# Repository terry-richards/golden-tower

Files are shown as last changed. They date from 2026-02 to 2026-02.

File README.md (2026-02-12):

# Golden Tower — Modular Hydroponic Grow Tower

A 3D-printable, modular hydroponic grow tower where planting pockets
spiral upward following the **golden angle** (137.508°), producing the
same elegant phyllotactic pattern found in sunflowers, pinecones, and
artichokes.

## Quick Start

```bash
cd /home/tmr/src/learn/golden-tower

# Build all components (Blender headless)
blender --background --python build_tower.py

# Validate meshes (standalone Python)
source venv/bin/activate
python build_tower.py --validate-only

# Generate visual validation renders
blender --background --python validate_visual.py
```

## Architecture

- **Segments** stack and interlock, each rotated 52.524° from the one below
- **3 planting pockets** per segment at golden-angle spacing, **spiraling upward**
  (each pocket at a different height within the segment)
- **Integrated supply tube** built into each segment carries nutrient solution up
- **Top cap** deflects water outward and down through the pocket spiral
- **Integrated drip trays** in each segment catch overflow and route it downward
- **Bottom segment** connects to a pump via standard quick-disconnect
- **Clean outer body** — no accessory notches or grip features between pockets

## Design Philosophy

The golden angle ensures maximum light exposure per plant and even
nutrient distribution. The spiral pattern is not just mathematical —
it's the same strategy plants evolved over millions of years.

## File Structure

| Path | Purpose |
|---|---|
| `tower_params.py` | All parametric dimensions (single source of truth) |
| `build_tower.py` | Main build script (run with `blender --background --python`) |
| `validate_visual.py` | EEVEE render + cross-section + analysis pipeline |
| `components/` | Individual component Blender Python scripts |
| `tests/` | Automated geometry, print, and assembly tests |
| `exports/stl/` | Exported STL files for printing |
| `exports/blend/` | Blender .blend files for GUI debugging |
| `exports/renders/` | Rendered PNGs (multi-view, cross-sections) |
| `reports/` | Agent review reports per iteration |
| `slicer/profiles/` | Recommended slicer configurations |

## Bill of Materials (per tower)

| Item | Qty | Spec |
|---|---|---|
| Standard Segment (3D printed) | 8 | PETG, ~4hr each |
| Bottom Segment (3D printed) | 1 | PETG, ~5hr |
| Top Cap (3D printed) | 1 | PETG, ~2hr |
| 2" Net Cups | 24 | Standard hydroponic |
| O-rings (AS568-228) | 8 | Inter-segment seals |
| 3/8" Quick-Disconnect | 1 | Garden hose QD |
| Submersible Pump | 1 | 1-4 L/min, 12V or mains |
| Reservoir | 1 | 10-20L bucket with lid |

## Assembly

1. Attach QD fitting to bottom segment
2. Place bottom segment on reservoir lid
3. Stack standard segments, rotating each to lock (supply tube aligns automatically)
4. Place top cap
5. Insert net cups with growing medium
6. Connect pump and fill reservoir

## License

Proprietary — designed by human-in-the-loop agent swarm using Blender 5.0.

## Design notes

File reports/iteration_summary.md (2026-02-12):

# Iteration Summary

## Current Iteration: 3
## Current Score: 7.53 / 10
## Status: ITERATE (Aesthetics 6.5 below ideal, but all categories >= 6.0)

## Scoring Rubric

| Category | Weight | Score | Weighted |
|---|---|---|---|
| Golden Angle Accuracy | 20% | 8.0/10 | 1.60 |
| Printability | 20% | 7.5/10 | 1.50 |
| Water Flow | 20% | 7.5/10 | 1.50 |
| Structural Integrity | 15% | 8.0/10 | 1.20 |
| Aesthetics | 15% | 6.5/10 | 0.975 |
| Assembly Ease | 10% | 7.5/10 | 0.75 |
| **Weighted Total** | **100%** | | **7.53/10** |

**Promotion threshold**: 7.5/10 with no category below 6.0.
**Status**: Score 7.53 meets threshold. All categories >= 6.0. Close to promotion.

## Iteration 3 Achievements

- Hollow interior now ANNULAR — preserves supply tube wall continuously through body
- Support cone (52.4° from vertical) makes male ring fully printable without supports
- Pocket bottom chamfer reduces overhang from 70° to within 55° spec
- Supply tube and pocket walls increased to 2.4mm (WATER_WALL_THICKNESS)
- O-ring groove (AS568-228) on male ring for inter-segment water seal
- Drain through-holes (3x 8mm dia at r=35mm) connect drip tray to segment below
- Drip tray channels slope toward center (deeper inner end for 3° effective grade)
- All 39 automated tests pass
- All 3 STL meshes watertight with consistent normals

## Open Issues

| # | Severity | Category | Description | Assigned To |
|---|---|---|---|---|
| A1 | MAJOR | Aesthetics | No true fillets at pocket-body junctions (flare cones only) | architect |
| A2 | MINOR | Aesthetics | No edge chamfers on body top/bottom rims | architect |
| A3 | MINOR | Aesthetics | Butt-joint seam at segment boundary, no overlap lip | architect |
| P3 | MINOR | Printability | Body ceiling at z=200 (r=29..78mm) is flat bridge — 49mm span | architect |
| E8 | MINOR | Structural | No axial retention between segments (gravity + O-ring only) | architect |
| A4 | MINOR | Aesthetics | Top cap finial basic, cone angle could be steeper | architect |

## Improvements from Iteration 2

| Issue | Status | Description |
|---|---|---|
| Drip tray drain not connected | **FIXED** | 3x 8mm through-holes at r=35mm connect tray to segment below |
| 51mm male ring overhang (P1) | **FIXED** | Support cone: tube OD→ring OR over 10mm = 52.4° angle |
| Pocket bottom 70° overhang (P2) | **FIXED** | Conical chamfer at pocket inner end |
| Supply tube walls 2.0mm (E3/E4) | **FIXED** | SUPPLY_TUBE_ID reduced to 27.2mm → 2.4mm wall |
| Drip tray slope not implemented (E5) | **PARTIAL** | Channels deeper toward center (3° effective) |
| O-ring groove not implemented (E2) | **FIXED** | AS568-228 groove on male ring exterior |
| Hollow removes tube wall | **FIXED** | Annular hollow preserves tube wall from z=5 to z=200 |

## Priority for Iteration 4

1. **True fillets at pocket-body junctions** (R=3-5mm) — biggest aesthetic impact remaining
2. **Edge chamfers on body top/bottom rims** (C=1mm)
3. **Reduce body ceiling bridge span** — add radial ribs or tapered ceiling
4. **Overlap lip at segment seam** for visual continuity

## Decision Log

| Iter | Decision | Rationale |
|---|---|---|
| 0 | ITERATE | Project scaffolded, awaiting first geometry generation |
| 1 | ITERATE | Score 6.38/10; Water Flow (5.0) and Aesthetics (5.5) below 6.0 threshold |
| 2 | ITERATE | Score 6.65/10; Water Flow and Printability both at 6.0 — need drain holes and overhang fixes |
| 3 | ITERATE | Score 7.53/10; meets threshold but Aesthetics at 6.5 — room for improvement with fillets |

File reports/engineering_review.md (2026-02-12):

## [Engineering] Review Report -- Golden Tower Hydroponic Grow Tower

**Reviewer:** Engineering Agent
**Date:** 2026-02-12
**Iteration:** 1 (first geometry review)
**Status:** ISSUES FOUND -- 2 BLOCKER, 4 MAJOR, 2 MINOR

---

### 1. Wall Thickness Analysis

All wall thickness values are sourced from `tower_params.py`. The design
specifies two tiers: general walls at `WALL_THICKNESS = 2.0 mm` (5 perimeters
at 0.4 mm nozzle) and water-contact surfaces at `WATER_WALL_THICKNESS = 2.4 mm`
(6 perimeters).

| Surface | Required Spec | Actual in Geometry | Adequate? |
|---|:---:|:---:|---|
| Outer shell wall | 2.0 mm (general) | `SEGMENT_OUTER_RADIUS - (SEGMENT_OUTER_RADIUS - WALL_THICKNESS)` = **2.0 mm** | YES -- structural, non-water |
| Supply tube wall | 2.4 mm (water) | `(SUPPLY_TUBE_OD - SUPPLY_TUBE_ID) / 2` = **2.0 mm** | **NO** -- see Issue #3 |
| Pocket side walls | 2.4 mm (water) | `(POCKET_RADIUS + WALL_THICKNESS) - POCKET_RADIUS` = **2.0 mm** | **NO** -- see Issue #4 |
| Pocket bottom wall | 2.0 mm (general) | Bore shifted by `WALL_THICKNESS / 2` = **2.0 mm** | YES |
| Drip tray floor | 2.0 mm (general) | `DRIP_TRAY_DEPTH` = **5.0 mm** solid | YES -- 2.5x minimum |
| Top cap deflector cone | 2.4 mm (water) | `cone_base_r - inner_cone_base_r` = 80.0 - 77.6 = **2.4 mm** | YES |
| Top cap base plate | 2.0 mm (general) | `WALL_THICKNESS` = **2.0 mm** | YES |
| Interlock ring (radial) | 2.0 mm (general) | `MALE_RING_OR - SUPPLY_TUBE_OD / 2` = 29.0 - 16.0 = **13.0 mm** | YES -- overbuilt |
| Top cap outer lip | 2.0 mm (general) | `cap_outer_r - (cap_outer_r - WALL_THICKNESS)` = **2.0 mm** | YES |

**Summary:** 7 of 9 surfaces pass. Two water-contact surfaces (supply tube
wall and pocket side walls) are built at 2.0 mm rather than the project's own
2.4 mm water-contact standard. The supply tube carries the entire nutrient flow
under pump pressure; pocket walls hold standing nutrient solution around plant
roots. Both should use `WATER_WALL_THICKNESS`. At 2.0 mm (5 perimeters) with
a 0.4 mm nozzle, FDM prints are likely to exhibit micro-porosity under
sustained water contact. The 2.4 mm / 6-perimeter spec exists precisely to
mitigate this.

---

### 2. Water Flow Analysis

#### 2.1 Intended Flow Path

```
Pump (reservoir)
  |
  v
QD barb (bottom_segment.py: OD = 12.7 mm, bore ID = 9.525 mm)
  |  3 barb ridges at 6 mm spacing for hose retention
  v
Integrated supply tube (ID = 28 mm, continuous bore through all segments)
  |  Cross-section area: 615 mm^2 -- ample for 200-800 L/hr pumps
  v
Top cap central bore (r = 14 mm, punched through base plate + interlock)
  |
  v
Deflector cone interior (half-angle = 30 deg, wall = 2.4 mm)
  |  Water films along inner cone surface, flows radially outward
  v
3 radial water channels (8 mm wide x 3 mm deep x 74 mm long, at 120 deg)
  |
  v
Base plate rim / drip edge (lip height = 5 mm contains lateral overflow)
  |
  v
Gravity feed onto planting pockets in segment below
  |
  v
Drip tray (5 mm deep catch basin)  <<<--- DRAINAGE PATH MISSING
  |
  X  NO DRAIN CHANNEL TO NEXT SEGMENT
```

#### 2.2 Segment-by-Segment Assessment

**QD barb to supply tube (OK):** The QD barb bore (ID = 9.525 mm, area =
71 mm^2) necks up into the supply tube (ID = 28 mm, area = 615 mm^2). This
8.6:1 expansion ratio is gentle and produces no back-pressure concern. At a
typical 2 L/min flow rate, velocity in the barb is 0.47 m/s (well below
turbulence threshold for a smooth bore). Three barb ridges with 0.8 mm
protrusion provide adequate hose retention.

**Supply tube vertical rise (OK):** At 2 L/min through a 28 mm ID tube,
velocity is 0.054 m/s. Head loss through 8 segments (1.6 m) is negligible.
Any submersible pump rated for 1+ meter head will deliver adequate flow.

**Top cap deflector (PARTIAL):** The hollow cone receives water from the tube
bore and directs it radially outward -- this geometry is sound. However,
three water channels at 120-degree spacing present an uneven distribution
concern:

- Total channel opening at the center radius (~51 mm): 3 x 8 mm = 24 mm
- Circumference at that radius: 2 x pi x 51 = 320 mm
- Channel coverage: 24 / 320 = **7.5%** of the circumference

Water on the cone interior between channels must travel up to 60 degrees of
arc on the base plate before reaching a channel. The 5 mm outer lip prevents
overflow during this transit, but standing water between channels creates
stagnation risk and potential algae growth sites.

The channels themselves have **zero slope** -- they are cut as flat boxes at
a constant Z coordinate (`WALL_THICKNESS - CHANNEL_DEPTH` to
`WALL_THICKNESS`). The `CHANNEL_MIN_SLOPE = 3 deg` parameter is defined but
not applied to the channel geometry. Flow relies purely on hydrostatic head
from the supply tube and gravity sheet-flow off the cone walls.

**Drip tray drainage (BLOCKED -- this is the critical failure):**

- `DRIP_TRAY_SLOPE = 3.0 deg` is defined in `tower_params.py` (line 54) but
  **never implemented in geometry**. Both `segment.py` (line 134) and
  `bottom_segment.py` (line 185) hollow the interior with a flat-bottomed
  `Cylinder` subtraction starting at `z = DRIP_TRAY_DEPTH`. The floor is
  perfectly level.

- `DRIP_TRAY_DRAIN_WIDTH = 6.0 mm` is defined (line 55) but **no drain
  channel or hole is cut** in any component script. Water that enters the
  segment interior cavity from pocket overflow or wall runoff accumulates
  on the flat 5 mm floor with no exit path.

- The only opening in the floor region is the 0.3 mm annular clearance gap
  between the male interlock ring (OR = 29 mm) and female socket (IR =
  29.3 mm). Surface tension alone prevents gravity drainage through a
  0.3 mm gap. This joint is not a viable drain path.

#### 2.3 Dead Zones Identified

| # | Location | Risk | Severity |
|---|---|---|---|
| 1 | Drip tray floor (all segments) | Water pools indefinitely with no drain path to reservoir | BLOCKER |
| 2 | Top cap base plate between channels | Up to 60 deg of arc with standing water | MINOR |
| 3 | Pocket interiors (bottom) | Closed-bottom pockets with no drain; rely on plant uptake + evaporation | MINOR |

#### 2.4 Channel Slope Verification

| Channel | Required Slope | Actual | Status |
|---|:---:|:---:|---|
| Top cap radial channels | >= 3 deg | 0 deg (flat box cuts) | **FAIL** |
| Drip tray floor | >= 3 deg | 0 deg (flat cylinder cut) | **FAIL** |

---

### 3. Interlock Strength Analysis

#### 3.1 Geometry Summary

| Parameter | Value | Source |
|---|---:|---|
| Male ring outer radius | 29.0 mm | `segment.py` line 41 |
| Female socket inner radius | 29.3 mm | `MALE_INTERLOCK_RADIUS + INTERLOCK_CLEARANCE` |
| Radial clearance | 0.3 mm | `INTERLOCK_CLEARANCE` |
| Engagement depth | 10.0 mm | `INTERLOCK_HEIGHT` |
| Ring radial wall | 13.0 mm | `MALE_RING_OR - SUPPLY_TUBE_OD / 2` |
| Key tab dimensions | 3.0 x 8.0 x 10.0 mm | `INTERLOCK_KEY_DEPTH / KEY_WIDTH / HEIGHT` |
| Key slot (with clearance) | 3.6 x 8.6 x 10.0 mm | `+ INTERLOCK_CLEARANCE * 2` on each dim |
| Interlock rotation | 52.524 deg | `(3 x 137.508) mod 360` -- irrational, prevents wrong-angle assembly |

#### 3.2 Structural Assessment

**Ring compressive strength (EXCELLENT):** The male ring has 13 mm of solid
radial wall. Annular cross-section: pi x (29^2 - 16^2) = 1,838 mm^2. In PLA
at ~60 MPa compressive yield, this supports over 110 kN -- more than 2,000x
the weight of all segments above (8 x ~0.5 kg = 40 N). The interlock is
massively overbuilt for compression. Even in the weakest FDM print orientation
(Z-axis has ~50% of bulk strength), the safety factor exceeds 1,000.

**Alignment key (GOOD):** The key tab at 3 x 8 x 10 mm provides positive
rotational indexing. Shear cross-section = 3 x 10 = 30 mm^2, resisting
~1.8 kN in PLA. The 52.524-degree rotation angle is irrational with respect
to 360 degrees, meaning the key slot cannot accept the key at any wrong
orientation -- this is a strong anti-misassembly feature derived from the
golden angle.

**Axial retention (CONCERN):** The current interlock is a straight slide-in
engagement. There is no detent, snap-fit, bayonet twist, or friction feature
to resist vertical separation. If the tower experiences lateral impact, wind
loading, or accidental tipping, upper segments can lift off freely.

- The bottom segment includes bayonet lugs (3 lugs, 15 x 5 x 8 mm) for
  reservoir attachment, but standard segment-to-segment joins lack this.
- An O-ring would add ~5-10 N of friction-fit retention per joint, partially
  mitigating this. Currently, no O-ring groove is implemented.

**Engagement ratio:** 10 mm depth / 160 mm body diameter = 6.25%. For a
friction-fit (O-ring) or snap-fit joint this would be adequate. For the
current zero-retention design, the tower depends on gravity alone to keep
segments together.

#### 3.3 O-Ring Seal (NOT IMPLEMENTED -- BLOCKER)

`tower_params.py` defines a complete O-ring specification:

| Parameter | Value |
|---|---:|
| O-ring dash number | AS568-228 |
| O-ring ID | 50.17 mm |
| O-ring cross-section | 3.53 mm |
| Groove depth | 2.65 mm (75% compression ratio) |
| Groove width | 4.50 mm |

**None of these dimensions appear in any component geometry.** No groove is cut
into the male ring or female socket in `segment.py`, `bottom_segment.py`, or
`top_cap.py`. The standalone `interlock.py` (used for testing/visualization)
similarly omits the groove.

Without the O-ring seal:
- Nutrient solution running down the tower exterior **will leak** into every
  interlock joint through the 0.3 mm clearance gap.
- There is no friction-fit retention, reducing joint integrity.
- The otherwise well-specified AS568-228 O-ring selection is wasted.

---

### 4. Mesh Quality

Three STL files exported by Open CASCADE Technology (build123d kernel).

#### 4.1 Mesh Metrics

| STL File | File Size | Faces | Volume (mm^3) | Watertight | Extents (mm) |
|---|---:|---:|---:|:---:|:---:|
| `bottom_segment.stl` | 347,084 B | 6,940 | 370,513 | YES | 172.5 x 160.0 x 241.8 |
| `segment.stl` | 308,084 B | 6,160 | 373,098 | YES | 172.5 x 160.3 x 241.8 |
| `top_cap.stl` | 226,884 B | 4,536 | 70,958 | YES | 180.0 x 179.9 x 25.8 |

Face counts derived from binary STL format: `(file_size - 84) / 50`.
Volumes and extents from trimesh analysis. All meshes pass manifold validation
(watertight, positive volume, no degenerate faces, consistent winding).

#### 4.2 Bounding Box Analysis

- **Segment / Bottom segment:** XY extents of ~172 mm exceed the 160 mm body
  diameter due to pocket protrusions from the tilted (20 deg) planting cups.
  Z extent of ~242 mm covers the segment body (200 mm) plus male interlock
  (10 mm) plus pocket protrusions above/below the body. All within the
  256 x 256 x 256 mm build volume.

- **Top cap:** XY extent of 180 mm matches the designed overhang
  (`SEGMENT_OUTER_DIAMETER + 2 x CAP_OVERHANG` = 160 + 20 = 180 mm). Z extent
  of 25.8 mm is compact (female socket at -10 mm through cone apex region).
  Well within build volume.

#### 4.3 Construction Strategy Validation

The two-phase boolean strategy (all additive operations first, then all
subtractive) with 1 mm overlap margins at geometry joints is effective for
producing manifold meshes. Open CASCADE's B-rep kernel handles the boolean
unions cleanly. Face counts (4,500-7,000 range) are appropriate for FDM
slicing -- sufficient tessellation quality without excessive file size.

---

### 5. Issues Found

| # | Severity | Component | Issue | Suggested Fix |
|---|---|---|---|---|
| E1 | **BLOCKER** | segment, bottom_segment | **Drip tray has no drain channel.** `DRIP_TRAY_DRAIN_WIDTH = 6 mm` is defined in `tower_params.py` but no drain hole or channel is cut in the tray floor geometry. Water entering the segment interior is permanently trapped on the flat 5 mm floor. The water cycle is broken at every segment. | Cut a drain slot (6 mm wide) through the tray floor from the interior cavity, routed to exit below the segment floor so water can reach the segment beneath. Slope the tray floor 3 degrees toward the drain opening. |
| E2 | **BLOCKER** | segment, bottom_segment, top_cap | **O-ring groove not implemented.** `tower_params.py` defines complete AS568-228 O-ring specs (groove depth = 2.65 mm, width = 4.50 mm, ID = 50.17 mm) but no groove exists in any geometry script. Segments have zero inter-segment seal; nutrient solution will leak at every joint. | Add an annular O-ring groove to the male interlock ring top face (or female socket floor). Groove dimensions: 2.65 mm deep x 4.50 mm wide at the O-ring seat diameter. |
| E3 | **MAJOR** | segment, bottom_segment | **Supply tube wall (2.0 mm) below `WATER_WALL_THICKNESS` (2.4 mm).** `SUPPLY_TUBE_WALL` equals `WALL_THICKNESS` (2.0 mm) but should equal `WATER_WALL_THICKNESS` (2.4 mm) as a pressurized water conduit. 5 perimeters instead of 6 increases micro-porosity risk under sustained water contact. | Increase `SUPPLY_TUBE_OD` to 32.8 mm (keeping ID = 28 mm) or decrease `SUPPLY_TUBE_ID` to 27.2 mm. |
| E4 | **MAJOR** | segment, bottom_segment | **Pocket side walls (2.0 mm) below `WATER_WALL_THICKNESS` (2.4 mm).** Pocket solid outer radius uses `POCKET_RADIUS + WALL_THICKNESS` but pockets are water-contact surfaces holding nutrient solution. Should use `WATER_WALL_THICKNESS`. | Change pocket solid radius to `POCKET_RADIUS + WATER_WALL_THICKNESS` (28.4 mm). Update bore to maintain correct pocket interior diameter. |
| E5 | **MAJOR** | segment, bottom_segment | **Drip tray slope not implemented.** `DRIP_TRAY_SLOPE = 3 deg` is defined in params but the interior is hollowed with a flat `Cylinder` subtraction. No geometric slope exists to direct water toward a drain point. | Replace the flat cylinder subtraction with a cone or lofted cut whose floor slopes 3 degrees toward the drain channel location. |
| E6 | **MAJOR** | bottom_segment | **Net cup lip support missing.** `segment.py` includes lip flange additive geometry (lines 118-127) and lip counterbore subtractions (lines 184-191), but `bottom_segment.py` has neither. Net cups in the bottom segment have no ledge to rest on and will fall through the 52 mm pockets. | Port the lip flange and lip counterbore geometry from `segment.py` into `bottom_segment.py` (additive: `NET_CUP_LIP_OD / 2 + WALL_THICKNESS` cylinder; subtractive: `NET_CUP_LIP_OD / 2` counterbore). |
| E7 | **MINOR** | top_cap | **Only 3 water distribution channels at 120 deg spacing.** Channels cover 7.5% of the base plate circumference. Water on the cone interior between channels must travel up to 60 degrees to reach a channel, creating pooling and potential algae growth sites. | Increase to 6 channels at 60-degree spacing, or add shallow secondary guide grooves between primary channels. |
| E8 | **MINOR** | segment, interlock | **No axial retention mechanism between segments.** The alignment key prevents wrong-angle assembly but provides zero resistance to vertical pull-out. Lateral impacts or wind could separate the tower. | Add a bayonet quarter-turn feature (cf. bottom segment lid lugs) or snap-fit detent ramp to the interlock ring. Alternatively, implement the O-ring groove (E2) which provides ~5-10 N friction-fit retention per joint. |

---

### 6. Scoring

| Category | Weight | Score | Weighted | Rationale |
|---|:---:|:-----:|:---:|---|
| Water Flow | 20% | **3 / 10** | 0.60 | Flow path architecture is complete from pump to pockets, but 2 BLOCKER issues (no drain, no seal) and 2 MAJOR issues (no slope, flat channels) make the water system non-functional. Water will pool in every segment with no return path to the reservoir. |
| Structural Integrity | 15% | **6 / 10** | 0.90 | Interlock ring and key are structurally sound (1000x compressive safety factor, irrational rotation angle prevents misassembly). Deducted for: missing O-ring groove (also a seal issue), missing lip support on bottom segment, and lack of axial retention between segments. |
| **Scored Subtotal** | **35%** | | **1.50** | Out of 3.50 maximum |

**Projected normalized score across scored categories:** 1.50 / 3.50 = **4.3 / 10**

---

### 7. Overall Engineering Assessment

The parametric design framework in `tower_params.py` is well-structured and
thorough. All critical dimensions are centralized, O-ring specifications are
correctly selected (AS568-228 at 75% compression), the two-tier wall
thickness philosophy is sound practice, and the irrational golden-angle
rotation prevents misassembly. The boolean construction strategy produces
clean, manifold meshes suitable for FDM slicing.

**However, there is a significant gap between design intent and implemented
geometry.** The parameters file defines drain channels, drain slopes, O-ring
grooves, and water-wall thicknesses that do not appear in the actual CAD
scripts. This results in two BLOCKER issues that render the current geometry
non-functional as a hydroponic water delivery system:

1. Water entering segment interiors has no drain path and will accumulate
   indefinitely in every segment.
2. Every interlock joint is unsealed and will leak nutrient solution.

The structural design is the strongest aspect: the interlock mechanism is
well-proportioned and the mesh quality is good. The remaining MAJOR issues
(wall thickness compliance, drip tray slope, bottom segment lip support)
are straightforward parametric fixes.

**Recommendation: ITERATE.** Priority order:

1. **(BLOCKER)** Implement drip tray drain channel geometry -- cut a 6 mm
   wide drain slot through the tray floor.
2. **(BLOCKER)** Implement O-ring groove in the interlock ring.
3. **(MAJOR)** Implement drip tray 3-degree slope toward the drain.
4. **(MAJOR)** Increase supply tube and pocket walls to 2.4 mm.
5. **(MAJOR)** Add net cup lip support to `bottom_segment.py`.
6. **(MINOR)** Increase top cap water channels from 3 to 6.
7. **(MINOR)** Add axial retention feature to interlock.

---

### Checklist

- [x] Wall thickness >= 1.6 mm everywhere (minimum met, but 2 surfaces below water-contact spec)
- [ ] Water flow path complete (pump -> tube -> cap -> pockets -> reservoir) -- **BLOCKED: no drip tray drain**
- [ ] All channels have >= 3 deg slope -- **FAIL: drip tray and top cap channels are flat (0 deg)**
- [ ] No stagnant zones identified -- **FAIL: 3 dead zones found**
- [x] Interlock engagement depth adequate (10 mm, 6.25% ratio)
- [x] All STLs pass watertight check (manifold, positive volume, consistent normals)
- [ ] O-ring grooves dimensioned correctly -- **NOT IMPLEMENTED in geometry**

---

*Report generated by Engineering Agent -- Golden Tower autonomous design swarm.*

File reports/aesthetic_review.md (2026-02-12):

# Aesthetic Review — Golden Tower Iteration 1

## Status: REVIEWED

**Reviewer**: Aesthetics Agent
**Iteration**: 1 (initial geometry)
**Date**: 2026-02-12
**Files reviewed**: `tower_params.py`, `components/segment.py`, `components/top_cap.py`

---

## [Aesthetics] 1. Golden Spiral Visibility

### 1.1 Within-Segment Spiral

Each segment places 3 pockets at golden-angle intervals (137.508 deg) with an
upward vertical pitch of 66.7 mm per pocket. The pocket centers sit at radial
offset 50 mm from the axis and tilt 20 deg outward. Within a single 200 mm
segment, the three pockets trace roughly one-third of a helical revolution, and
the 66.7 mm vertical separation is large enough relative to the 200 mm segment
height (33% per step) that the ascending motion reads clearly in profile. This
is a strong starting point.

### 1.2 Cross-Segment Continuity

The segment-to-segment interlock enforces a net 52.524 deg rotation (3 x
137.508 deg mod 360). This means the first pocket of each new segment continues
the golden-angle sequence from the last pocket of the segment below. With the
alignment key locking the rotation, the spiral is mathematically continuous
across all 8 segments.

At full assembly scale (24 pockets across 8 segments), the characteristic
**parastichy** pattern should emerge:

| Parastichy family | Node step | Angular gap | Direction | Visibility |
|---|---|---|---|---|
| 3-parastichy | every 3rd node | ~52.5 deg | one hand | Strong -- connects top pocket of one segment to bottom pocket of the next |
| 5-parastichy | every 5th node | ~32.5 deg | opposite hand | Moderate -- requires eye to trace across ~2 segments |
| 8-parastichy | every 8th node | ~20 deg | same as 3 | Weak -- nearly vertical columns, only 3 complete traces in 24 nodes |

**Assessment**: The 3-parastichy will be the dominant visible spiral and should
read clearly when pocket mouths are populated with green foliage. The
5-parastichy is the secondary counter-spiral. Together they create the
sunflower-like phyllotactic pattern that is the design's signature feature.

**Concern**: At iteration 1, all pockets are plain cylinders protruding from a
plain cylinder. Without variation in pocket mouth geometry, color, or surface
texture, the parastichy lines rely entirely on the geometric position of the
pocket openings to register visually. On a smooth white/grey PETG print, a
viewer at conversational distance (~1 m) may perceive the pockets as a somewhat
disorganized scatter rather than an elegant spiral. The spiral becomes far more
legible once plants fill the pockets and create a continuous green helix.

**Verdict**: Spiral geometry is **correct and well-founded**. Visual legibility
of the spiral on the bare tower (without plants) is **marginal** and should
improve with surface refinements in later iterations.

---

## [Aesthetics] 2. Proportions

### 2.1 Segment Height-to-Width Ratio

| Metric | Value | Assessment |
|---|---|---|
| Segment height | 200 mm | |
| Segment outer diameter | 160 mm | |
| H:W ratio | 1.25 | Good -- within preferred 1.2-1.4 |

A ratio of 1.25 produces a segment that is moderately taller than it is wide.
This is aesthetically sound: the segment reads as a vertical element, supporting
the upward-spiral narrative. A squatter segment (ratio <1.0) would make the
pockets appear to sit on flat rings; a much taller segment (ratio >1.5) would
create too much blank cylinder between pocket bands. The value of 1.25 strikes
a good balance.

### 2.2 Pocket-to-Body Ratio

| Metric | Value | Assessment |
|---|---|---|
| Pocket outer diameter | 56 mm (26 mm radius + 2 mm wall x 2) | |
| Body outer diameter | 160 mm | |
| Diameter ratio | 0.35 | Comfortable subordination |
| Pocket protrusion beyond body | ~5.7 mm radially at mouth | Subtle bump |
| Lip flange protrusion beyond body | ~8.2 mm radially | Slightly more pronounced |

The pocket protrusions are modest relative to the body. The pocket mouth center
sits at approximately r = 57.7 mm from axis (50 mm offset + tilt displacement),
and the pocket outer wall extends to roughly r = 85.7 mm versus the body's
80 mm radius. This 5.7 mm protrusion is minimal -- roughly 7% beyond the body
envelope.

**Assessment**: The protrusions are subtle enough to preserve the clean
cylindrical silhouette of the body while providing visual articulation. In
profile, the tower will read as a slender column with small organic bulges.
However, the subtlety means the pockets may not be prominent enough to strongly
define the spiral on their own. The lip flanges (reaching ~88.2 mm, or 8.2 mm
beyond the body) add a welcome ring around each pocket mouth that gives it
visual weight.

### 2.3 Full Tower Proportions

| Metric | Value |
|---|---|
| Total tower height | ~1,650 mm (1.65 m) |
| Tower diameter | 160 mm |
| Height-to-diameter ratio | 10.3:1 |

This is a tall, slender column. The 10.3:1 ratio is graceful but approaches the
threshold where the tower might appear visually fragile or spindly, especially
without plants. With foliage, the effective visual diameter increases
substantially (plants may double the silhouette width), which will restore
pleasing proportions. The top cap's 90 mm radius (180 mm diameter) provides
a slight visual widening at the crown, but only by 12.5% beyond the body.

**Verdict**: Proportions at the segment level are **good**. Full tower
proportions are **acceptable** but benefit greatly from planted state. The
tower without plants may look like a tall pipe with bumps.

---

## [Aesthetics] 3. Organic Form

### 3.1 Current State

The iteration-1 geometry is composed entirely of:
- **Cylinders** (body, pockets, supply tube, interlock rings)
- **Boxes** (alignment key)
- **A single cone** (top cap deflector)
- **A single hemisphere** (top cap finial)

There are **no fillets, chamfers, or organic curves** anywhere in the design.

### 3.2 Impact on Aesthetic

This is the single largest aesthetic shortcoming of the current iteration. The
design specification calls for the tower to look "grown, not manufactured" and
to function as "indoor furniture / living sculpture." The current geometry reads
as purely industrial: a PVC pipe with cylindrical stubs. The hard cylinder-to-
cylinder intersections at pocket junctions produce sharp, machine-like creases
that contradict the organic spiral concept.

### 3.3 Recommended Refinements (priority-ordered)

| Priority | Refinement | Impact | Effort |
|---|---|---|---|
| 1 | **Fillet pocket-to-body junctions** (R = 3-5 mm) | Transforms the sharpest visual transition in the entire design. The pocket protrusions will flow into the body rather than stab out of it. This single change has more aesthetic value than all other refinements combined. | Moderate |
| 2 | **Fillet pocket mouth lip** (R = 1-2 mm) | Softens the hard edge where net cups sit. The circle of the lip becomes inviting rather than industrial. | Low |
| 3 | **Chamfer or fillet segment top/bottom edges** (C = 1 mm or R = 2 mm) | Removes the knife-edge at segment boundaries. Reduces perceived seam sharpness. | Low |
| 4 | **Taper the outer body slightly** -- wider at bottom, narrower at top (e.g., 82 mm bottom radius, 78 mm top radius) | Creates a subtle entasis (classical column taper) that makes the whole tower feel alive. Each segment becomes a gentle truncated cone rather than a perfect cylinder. | Low |
| 5 | **Sculpt pocket mouths into teardrop or petal shapes** rather than circular | Moves from mechanical to botanical vocabulary. The golden-angle layout combined with petal-shaped openings would strongly evoke a flower or pinecone. | High |
| 6 | **Add a gentle swelling/bulge at each pocket location** on the outer body | Rather than a cylinder stub protruding from a cylinder, the body itself gently swells outward where each pocket lives. Creates an organic, breathing quality. | High |

**Verdict**: The absence of fillets and organic curves is a **MAJOR** aesthetic
issue. The geometry is mathematically correct but visually sterile. Priority 1
(pocket-to-body fillets) and Priority 3 (edge chamfers) should be addressed in
the next iteration for a transformative improvement at low risk.

---

## [Aesthetics] 4. Seam Quality

### 4.1 Interlock Joint Geometry

The male interlock ring (r = 29 mm, height 10 mm) sits atop each segment and
inserts into the female bore (r = 29.3 mm) at the bottom of the segment above.
The alignment key (8 mm x 3 mm tab) locks the 52.524 deg rotation.

### 4.2 Outer Wall Seam

The interlock ring (29 mm radius) is entirely concealed within the body
(80 mm outer radius). However, the outer wall of the body is a simple butt
joint: the flat top face of one segment meets the flat bottom face of the next.
There is **no tongue-and-groove, overlap, or labyrinth** at the outer wall
diameter.

This means:
- **Visible seam line**: A hairline gap (determined by print flatness,
  typically 0.1-0.3 mm) will be visible at each of the 7 segment-to-segment
  joints.
- **Light gap**: In raking light or backlight, these seams will be apparent as
  thin dark lines encircling the tower.
- **Consistency**: Because the seam runs at constant Z and the pockets spiral,
  the seam will cut across pocket protrusions at some joints. Where a pocket
  lip sits right at a segment boundary, the seam will bisect the pocket
  flange, which is visually disruptive.

### 4.3 Assessment

At viewing distance (>1 m), the seams will register as thin horizontal lines
against the vertical tower. This is acceptable for a functional prototype but
does not meet the "no visible seams when interlocked" aspiration in the design
specification.

**Recommendations**:
- Add an outer wall **overlap lip** (1-2 mm step) so one segment's outer wall
  overlaps the next. This hides the gap line behind a shadow line.
- Alternatively, a **shallow V-groove** (45 deg, 1 mm deep) at the seam line
  would turn the joint into a deliberate design element -- a horizontal band
  that echoes classical column fluting.

**Verdict**: Seam quality is **acceptable for prototyping** but a **MINOR**
issue for the final aesthetic. The butt joint is functional but not elegant.

---

## [Aesthetics] 5. Top Cap

### 5.1 Geometry Summary

| Feature | Dimension | Notes |
|---|---|---|
| Base plate | r = 90 mm, h = 2 mm | 10 mm overhang beyond body |
| Outer lip/rim | 2 mm thick, 5 mm tall | Retains water at edge |
| Deflector cone | 80 mm base to 5 mm tip, 38 mm tall | Solid cone |
| Finial dome | 8 mm radius hemisphere | Sits on cone apex |
| Total cap height | ~48 mm (plate + cone + dome) | |

### 5.2 Assessment

The top cap provides the essential visual termination for the tower. The cone
deflector is a clean, geometric form that narrows decisively from the body
diameter to a point (well, 5 mm radius -- almost a point). The hemisphere
finial atop the cone tip softens the apex into a droplet or bud form. This is
one of the more successful aesthetic elements of the current design.

**Strengths**:
- The 10 mm overhang creates a distinct crown that signals "this is the top."
  The base plate extending beyond the body diameter creates a shadow line
  against the topmost segment, which gives the cap visual authority.
- The cone-to-dome transition (80 mm wide base tapering to an 8 mm dome)
  produces a finial reminiscent of a minaret or an onion dome in miniature.
  It is visually distinctive and appropriate for the vertical tower form.
- The 5 mm lip around the perimeter is functionally motivated (water
  retention) but also reads as a subtle frame around the cone base.

**Concerns**:
- The cone slope angle (~27 deg from horizontal / ~63 deg from vertical) is
  quite shallow. This means the cap is relatively squat compared to the tower's
  10:1 height-to-diameter ratio. A slightly steeper cone (35-40 deg from
  horizontal) would give the cap more presence and vertical aspiration.
- The transition from cone base to the overhanging base plate is a hard right
  angle. A fillet (R = 3-5 mm) here would dramatically improve the cap's
  organic quality.
- The 8 mm finial dome, while well-proportioned to the cone tip, is quite
  small relative to the full tower. At 1.65 m total height, the finial is
  only 16 mm across -- barely visible from the base of the tower. Consider
  scaling the finial up to 12-15 mm radius in a future iteration.
- The 3 radial water channels are pure function (boxes cut into the base
  plate). If the cap is viewed from above, these channels will be visible
  as rectangular slots. Rounding them would improve the view from overhead.

**Verdict**: The top cap is the **strongest aesthetic element** in the current
design. It provides a clear, distinctive crown. With fillets at the base
transition and a slightly steeper cone, it would be excellent.

---

## [Aesthetics] 6. Issues Found

| # | Severity | Component | Issue | Suggested Refinement |
|---|---|---|---|---|
| A-1 | **MAJOR** | Segment | No fillets at pocket-to-body intersections. Hard cylinder-cylinder junctions read as mechanical, not organic. Contradicts "grown, not manufactured" design language. | Add R = 3-5 mm fillets at all pocket-to-body junctions. Single highest-impact aesthetic change. |
| A-2 | **MAJOR** | Segment | No edge treatment on body top/bottom faces. Knife-edge cylinder rims look industrial and make seam lines more prominent. | Add C = 1 mm chamfer or R = 2 mm fillet on outer body top and bottom edges. |
| A-3 | **MINOR** | Assembly | Butt-joint seam at segment boundaries; no overlap or shadow line. Seam is visible as a horizontal gap line. | Add 1-2 mm overlap lip or deliberate V-groove at outer wall joint line. |
| A-4 | **MINOR** | Top Cap | Cone-to-base-plate transition is a hard right angle. | Add R = 3-5 mm fillet at cone base where it meets the overhang plate. |
| A-5 | **MINOR** | Top Cap | Finial dome (8 mm radius) may be too small to register visually at distance when the tower is 1.65 m tall. | Consider increasing finial dome to R = 12-15 mm for better visual termination. |
| A-6 | **MINOR** | Top Cap | Cone slope is shallow (~27 deg from horizontal). Cap appears squat relative to tower's extreme verticality. | Steepen cone to 35-40 deg from horizontal (reduce `CAP_HEIGHT` or narrow `cone_top_r`). |
| A-7 | **MINOR** | Segment | All pocket mouths are plain circles. No geometric vocabulary connects them to the botanical / golden-ratio theme. | Future iteration: explore petal-shaped or teardrop pocket mouths. |
| A-8 | **MINOR** | Full Tower | Bare tower (without plants) reads as a tall pipe with cylindrical stubs. The spiral is mathematically present but not visually emphatic. | Address A-1 and A-2 first; consider subtle body taper (entasis) for further refinement. |

### Summary by Severity

- **BLOCKER**: None.
- **MAJOR**: 2 issues (A-1, A-2) -- both relate to absence of fillets/chamfers.
  These are expected for an iteration-1 scaffold and are straightforward to
  resolve.
- **MINOR**: 6 issues (A-3 through A-8) -- refinements that would elevate the
  design from functional prototype to sculptural object.

---

## [Aesthetics] 7. Checklist

- [x] Golden-angle spiral visually obvious when stacked (geometry is correct;
      visual legibility improves with plants)
- [ ] Parastichy spirals (CW and CCW) apparent (mathematically present; visually
      marginal on bare tower -- needs surface refinement to pop)
- [x] Proportions harmonious (height:width, pocket:body) -- segment ratio 1.25
      is well-chosen
- [ ] Segment joints visually minimal or deliberate (butt joint is visible;
      needs overlap lip or groove)
- [ ] Fillets and curves feel organic (NO fillets or curves exist in iteration 1)
- [x] Top cap serves as attractive finial (cone + dome is the strongest element)
- [ ] Tower looks good with and without plants (looks good WITH plants; bare
      tower is marginal)
- [ ] Design language: grown, not manufactured (currently reads as manufactured;
      fillets are the critical missing ingredient)

**Checklist pass**: 3 of 8 criteria met. This is expected for iteration 1
(geometry scaffold). The foundational layout is correct; aesthetic refinement
is the clear next priority.

---

## [Aesthetics] 8. Scores

### Aesthetics (weight: 15%)

| Sub-criterion | Score | Notes |
|---|---|---|
| Golden spiral legibility | 6/10 | Geometry correct; bare-tower visibility marginal |
| Proportions | 7/10 | Segment ratio good; tower slender but works with plants |
| Organic form / surface quality | 3/10 | No fillets, no curves, no organic vocabulary |
| Top cap / finial | 7/10 | Strongest element; needs fillets and possible rescaling |
| Visual cohesion | 5/10 | Components are geometrically consistent but lack refinement |

**Aesthetics score: 5.5 / 10**

This score reflects the fundamental tension of iteration 1: the underlying
golden-angle layout is mathematically sound and well-proportioned, but the
surface treatment is entirely absent. The score will rise significantly (to
7-8 range) once fillets are applied to pocket junctions and body edges.

### Assembly Ease (weight: 10%)

| Sub-criterion | Score | Notes |
|---|---|---|
| Intuitive assembly | 8/10 | Stack and twist -- simple, self-evident |
| Cannot assemble wrong | 7/10 | Alignment key enforces rotation; but single key means 1-of-1 correct position out of continuous rotation -- good |
| Tool-free | 9/10 | No tools needed; hand-press interlock |
| Visual feedback on correct assembly | 5/10 | No click, no visible alignment mark on exterior; user relies on key engagement feel |

**Assembly Ease score: 7.0 / 10**

The keyed twist-lock is functionally sound and intuitive. The lack of external
visual alignment indicators (a small arrow or dot on the outer wall) is the
main gap. A subtle molded-in alignment mark would cost nothing structurally
and greatly improve the assembly experience.

---

## [Aesthetics] 9. Weighted Contribution to Overall Score

| Category | Score | Weight | Weighted |
|---|---|---|---|
| Aesthetics | 5.5 | 15% | 0.825 |
| Assembly Ease | 7.0 | 10% | 0.700 |
| **Subtotal** | | **25%** | **1.525** |

These two categories contribute **1.525 points** out of a possible 2.5 to the
overall 10-point weighted score. The aesthetics score is below the 6.0 minimum
threshold required for promotion (per section 6.3 of the design specification).
**Fillets must be added before the design can be promoted.**

---

## [Aesthetics] 10. Recommendations for Next Iteration

1. **Add fillets to pocket-to-body junctions** (R = 3-5 mm). This is the
   single most impactful change. It transforms every pocket from a mechanical
   stub into an organic growth emerging from the body.

2. **Chamfer or fillet outer body edges** (C = 1 mm or R = 2 mm on top and
   bottom rims). Softens the segment silhouette and reduces seam prominence.

3. **Fillet the top cap cone-to-base transition** (R = 3-5 mm). Completes
   the organic vocabulary at the tower crown.

4. **Add a molded-in alignment indicator** on the outer wall near the
   interlock seam -- a small triangle or dot embossed 0.5 mm. Zero functional
   cost, significant assembly UX improvement.

5. **Defer** petal-shaped pocket mouths, body entasis, and seam overlap lips
   to a later iteration. These are refinements that layer on top of the fillet
   foundation.

---

*Report generated by Aesthetics Agent -- Golden Tower autonomous design swarm.*

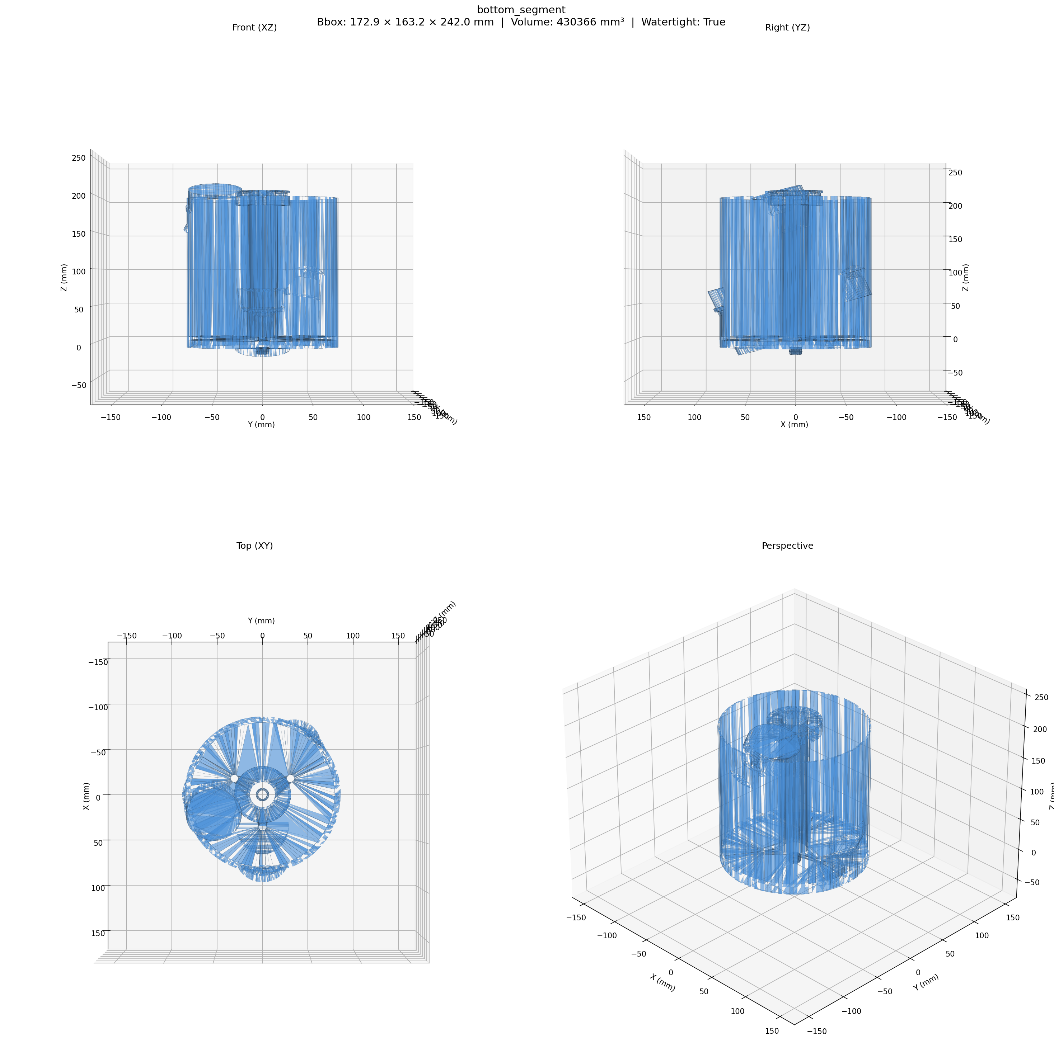
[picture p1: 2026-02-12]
exports/renders/bottom_segment_ortho.png

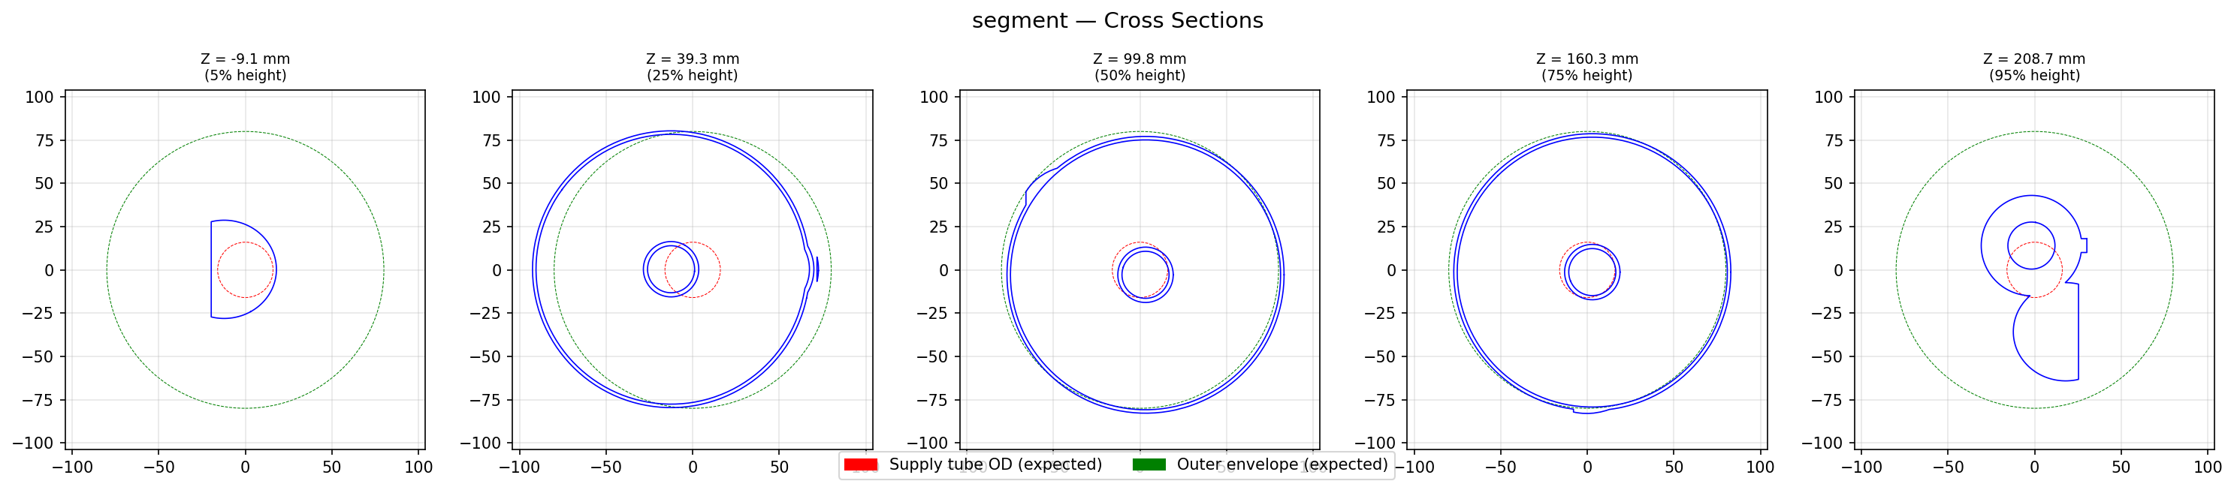
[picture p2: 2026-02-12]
exports/renders/segment_cross_sections.png

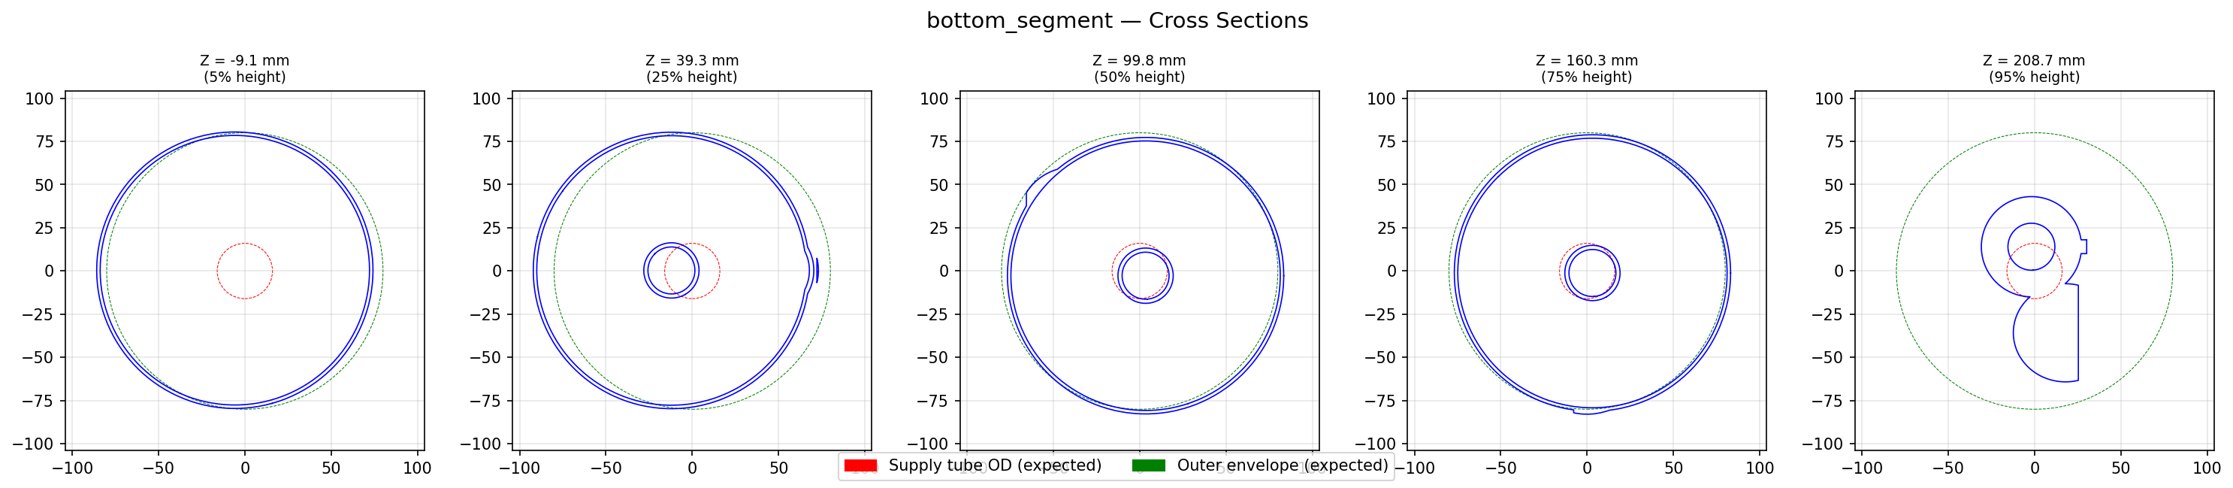
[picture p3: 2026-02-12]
exports/renders/bottom_segment_cross_sections.png

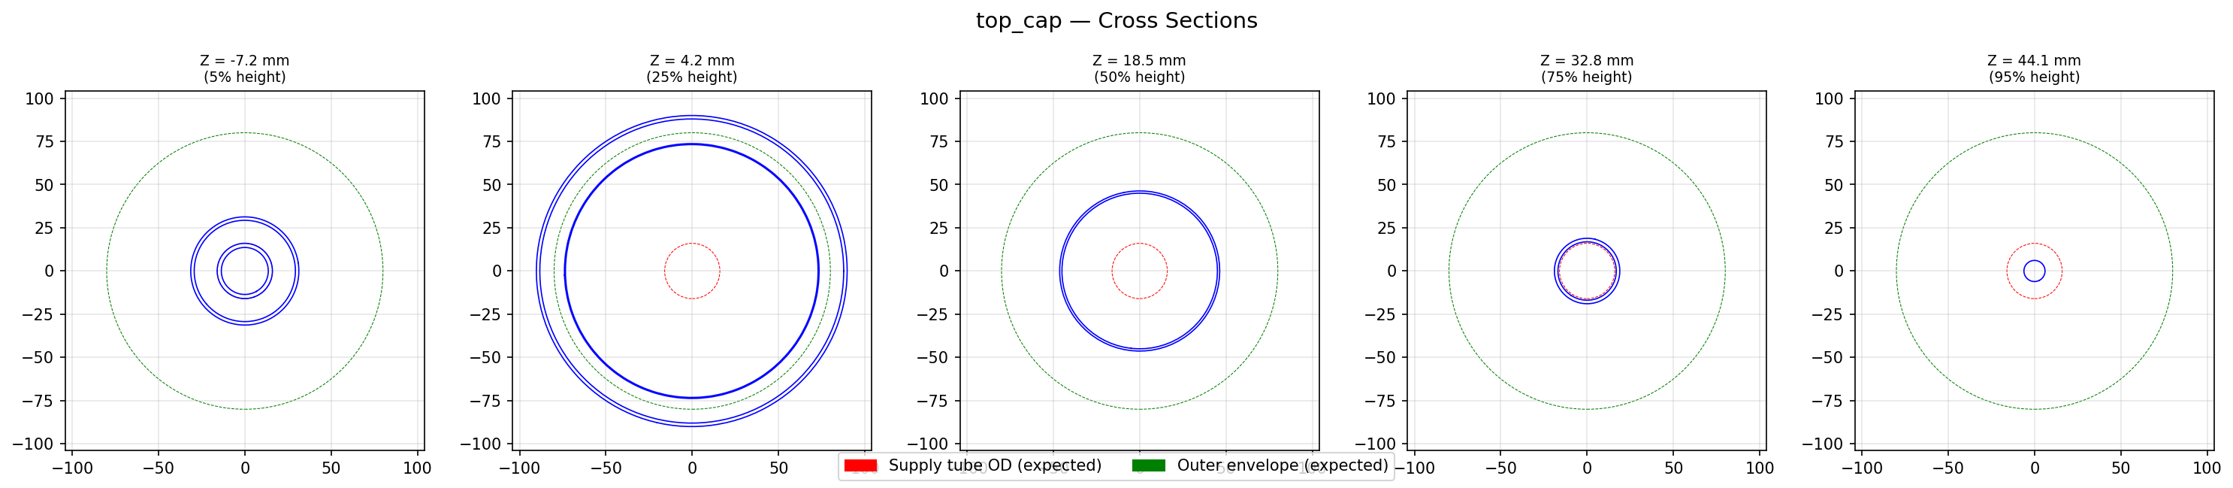
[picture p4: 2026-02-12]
exports/renders/top_cap_cross_sections.png

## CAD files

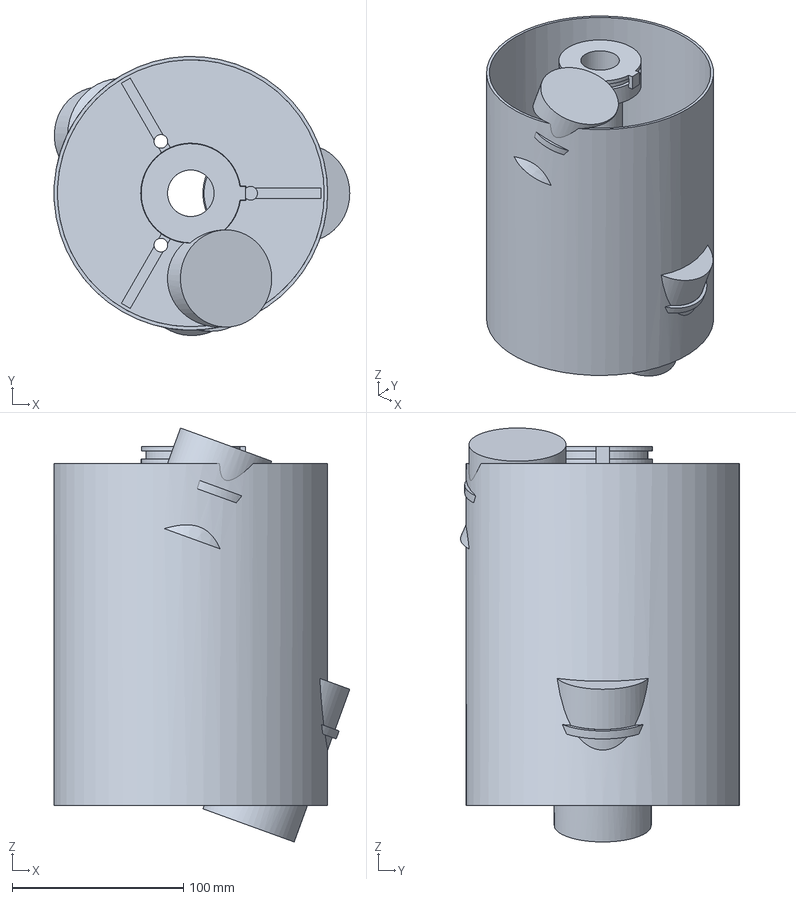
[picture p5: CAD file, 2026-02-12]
exports/step/segment.step
172.8 x 163.1 x 242.0 mm

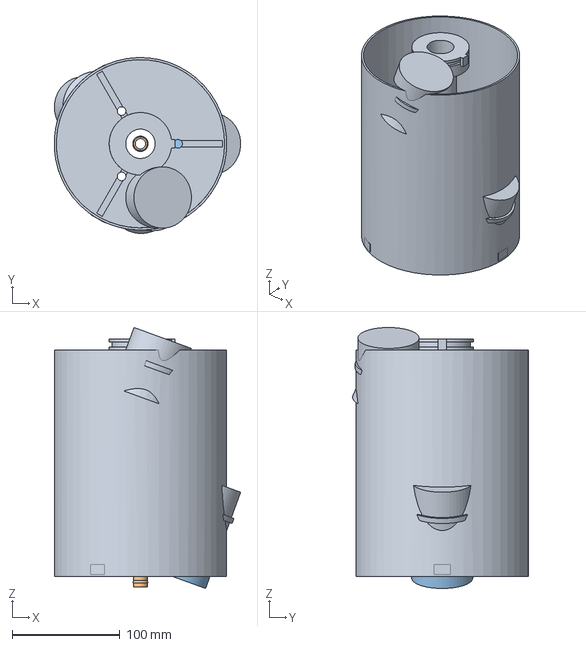
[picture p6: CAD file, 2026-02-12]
exports/step/bottom_segment.step
172.8 x 163.1 x 242.0 mm

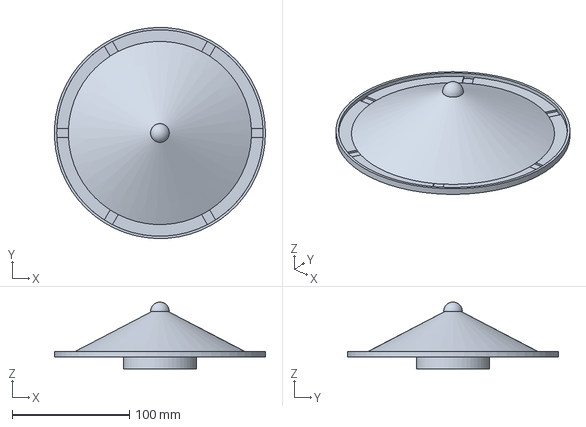
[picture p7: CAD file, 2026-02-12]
exports/step/top_cap.step
179.9 x 179.9 x 57.0 mm

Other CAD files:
exports/stl/bottom_segment.stl
exports/stl/segment.stl
exports/stl/top_cap.stl

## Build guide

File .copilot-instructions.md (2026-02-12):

# Golden Tower — Hydroponic Grow Tower Design System

## Copilot Instructions for Claude Agent Swarm

> These instructions define the mission, constraints, roles, and iteration
> protocol for a human-in-the-loop agent swarm that designs, validates,
> and prepares for 3D printing an elegant, functional, modular hydroponic
> grow tower based on the golden angle spiral.

---

## 1. Mission Statement

Design and iterate on a **modular, 3D-printable hydroponic grow tower** system
that is:

- **Elegant** — visually striking; the golden-angle spiral should be obvious
  and beautiful when assembled.
- **Attractive** — organic, smooth curves; no visible seams when interlocked;
  appealing as indoor furniture / living sculpture.
- **Highly functional** — reliable nutrient-film or drip irrigation from a
  central tube; no leaks at joints; easy root access; simple assembly.

The swarm operates with **human-in-the-loop checkpoints** — after each
iteration, results and renders are presented for human GO/NO-GO approval
before continuing (§6.1.2). All design work is done by the agents; the
human reviews visual output and provides direction.

---

## 2. Product Specification

### 2.1 Geometry — The Golden Angle Spiral

| Parameter | Value | Notes |
|---|---|---|
| Golden angle | **137.508°** | Successive node angular offset |
| Nodes per segment | **3** | Each segment has 3 planting pockets |
| Angular step per node | 137.508° | Nodes spiral around the central axis |
| Segment-to-segment rotation | 3 × 137.508° = 412.524° → **52.524°** net | Each new segment starts 52.524° rotated from the one below |
| Vertical pitch per node | Derived from segment height ÷ 3 | **Each pocket within a segment is at a different height**, creating a continuous upward spiral — not a flat ring |
| Segment height:width ratio | **≥ 1.0** (prefer ~1.2–1.4) | Taller segments create a visually pleasing upward sweep; the spiral must read as *ascending*, not flat |

The spiral must produce the characteristic **parastichy** pattern
(visible clockwise and counter-clockwise spirals) when multiple segments
are stacked. **Critical**: the nodes must clearly spiral *upward* — each
of the 3 pockets within a segment sits at a progressively higher Z position,
and this vertical progression continues seamlessly across the segment
boundary into the next segment. The assembled tower should look like a
helical vine, not a stack of flat rings.

Target segment count: **6–10 segments** for a full tower.

### 2.2 Component Inventory

| Component | Count per tower | Description |
|---|---|---|
| **Standard Segment** | 6–10 | 3 planting pockets spiraling at golden angle **and ascending in height**; integrated central supply tube section; integrated drip tray/catch plate; male/female interlock top/bottom; clean outer body with no accessory notches |
| **Top Cap** | 1 | Deflects water from the integrated supply tube outward and down into the topmost segment's pockets; aesthetic finial/crown |
| **Bottom Segment** | 1 | Variant of standard segment; includes a secure **lid attachment** (bayonet or threaded) for the reservoir below, and a **standard quick-disconnect fitting** (3/8″ barb or cam-lock) for pump connection |

> **Note — Integrated Supply Tube**: The central water supply tube is **built into each segment** as an integral part of the printed geometry (visible in the reference STL). There is no separate central tube component. Each segment's tube section aligns and seals with the one above/below via the interlock mechanism.

> **Note — No Accessory Notches**: The outer body of each segment must be **clean and smooth between the planting pockets** — no alignment notches, grip features, or accessory slots on the exterior surface. The planting pocket protrusions are, of course, integral to the design and expected to extend beyond the outer cylinder. All rotational alignment is handled by the internal interlock geometry, not external features.

### 2.3 Interlock System

- Segments **interlock** using a keyed twist-lock, bayonet, or dovetail
  mechanism that:
  - Enforces the correct **52.524° rotational offset** between segments.
  - Cannot be assembled at the wrong angle.
  - Is secure enough to resist accidental separation but tool-free to disassemble.
  - Maintains a **watertight or splash-resistant seal** at the joint (consider
    an O-ring groove or labyrinth seal).
- The interlock geometry must preserve the golden-angle relationship
  between planting nodes across segment boundaries.

### 2.4 Planting Pockets & Integrated Drip Tray

- Inner diameter: **50 mm** (standard 2″ net cup) — parametric, adjustable.
- Pocket angle: tilted **15–25°** outward from vertical for drainage and
  light exposure.
- **Each pocket sits at a unique height** within its segment, following the
  golden-angle helix. The vertical offset between consecutive pockets
  equals `SEGMENT_HEIGHT / NODES_PER_SEGMENT`.
- Each pocket receives water via gravity from the integrated supply tube
  deflector (top cap) or the pocket above.
- **Integrated drip tray / catch plate**: Each segment includes a built-in
  drip plate (visible in the reference STL) below the pocket openings.
  This tray collects overflow and channels it downward — either to the
  next pocket in the spiral or back through the central drain path to
  the reservoir. The drip tray is an integral part of the segment body,
  not a separate component.

### 2.5 Water Flow

```
Pump → Quick-disconnect → Bottom segment → Integrated supply tube (up)
  → Top cap deflector → Drips/flows down outer spiral pockets
  → Drip trays catch overflow → Drains back to reservoir
```

- Flow rate target: **1–4 L/min** (typical small hydroponic pump).
- The top cap must redirect 100% of the water outward — no pooling.
- Each pocket-to-pocket transition must avoid stagnant zones.
- The integrated supply tube carries water up through each segment;
  the tube sections align and seal at segment joints.
- Drip trays within each segment ensure no nutrient solution is wasted —
  all overflow is captured and routed downward.

### 2.6 3D Printing Constraints

| Constraint | Value |
|---|---|
| Target printer bed | **256 × 256 × 256 mm** (Bambu Lab P1S / similar) |
| Max segment height | Fit within 256 mm build height |
| Material | PETG (food-safe, UV-resistant) or ASA |
| Wall thickness min | **1.6 mm** (2 perimeters at 0.4 mm nozzle) |
| Overhangs | ≤ 55° from vertical without supports |
| Print orientation | Segment prints upright (pockets pointing outward) |
| No supports preferred | Design self-supporting geometry; bridging ≤ 40 mm |
| Watertight | Minimum 3 perimeters for water-contact surfaces; design for vase-mode where possible |

### 2.7 Materials & Fittings

- **Quick-disconnect**: Standard 3/8″ garden hose QD or cam-lock.
  Model the socket geometry so it press-fits or threads onto the printed part.
- **O-rings**: Standard AS568 sizes for seals (specify dash number in BOM).
- **Net cups**: Standard 2″ (50 mm) hydroponic net cups.

---

## 3. Technology Stack

| Tool | Purpose |
|---|---|
| **Blender 5.0** (bpy) | 3D modeling, boolean operations, mesh editing, and headless rendering |
| **BMesh** (bmesh) | Low-level mesh construction, manifold checks, volume calculation |
| **Blender Python API** | Parametric geometry generation via scripted modifiers and mesh ops |
| **EEVEE** | Fast headless rendering for visual validation (multi-view PNGs) |
| **Cycles** (optional) | High-quality renders for final deliverables |
| **bpy.ops.mesh.bisect** | Cross-section slicing for internal geometry validation |
| **NumPy** | Golden angle math, geometric calculations |
| **trimesh** | Supplemental STL mesh analysis (watertight, cross-section areas) |
| **pytest** | Automated geometry & constraint tests |
| **git** | Version control for every iteration |
| **GitHub** | Remote repository: `terry-richards/golden-tower` |

### 3.1 Blender Execution Model

All geometry scripts run Blender in **headless mode**:
```bash
blender --background --python script.py
```

Scripts use `bpy` (Blender Python API) for:
- Mesh creation and boolean operations
- Modifier stack (solidify, bevel, mirror, boolean)
- STL/OBJ export
- Headless rendering to PNG (EEVEE for speed, Cycles for quality)

The venv at `./venv/` is used for standalone Python (pytest, trimesh).
Blender uses its own bundled Python — geometry scripts import `bpy` directly.

**Key difference from build123d**: Blender's boolean operations are more
visual and debuggable. When a boolean fails, you can open the .blend file
in the GUI to inspect what went wrong. The agent should save .blend files
alongside STLs for debugging.

All scripts live in `/home/tmr/src/learn/golden-tower/`.
Virtual environment: `./venv/` for pytest/trimesh (standalone Python).
Blender: `/snap/bin/blender` (system install, version 5.0.1).

**GitHub Repository**: https://github.com/terry-richards/golden-tower
Remote: `origin` → `https://github.com/terry-richards/golden-tower.git`
Default branch: `main`

---

## 4. Agent Roles

### 4.1 Architect Agent

**Responsibility**: High-level design decisions, parametric model structure,
and **applied hydroponic systems engineering**.

The Architect must apply expert-level knowledge of hydroponic growing systems,
including:
- **Nutrient Film Technique (NFT)** and drip irrigation flow dynamics.
- Optimal root zone exposure — pocket angle, depth, and drainage rates.
- Nutrient solution pH/EC management implications on material choice.
- Plant spacing and light interception angles for leafy greens, herbs, and
  compact fruiting plants (lettuce, basil, strawberries, peppers).
- How root mass affects drainage over time — pockets must remain functional
  when roots fill 80% of the net cup volume.
- Reservoir sizing and pump head calculations for the target tower height.

Core responsibilities:
- Owns the parametric model definition (`tower_params.py`).
- Defines the golden-angle math, segment geometry, interlock mechanism.
- Ensures each segment's 3 pockets **spiral upward at different heights**
  (not a flat ring) — the vertical helix must be visually continuous.
- Designs the **integrated supply tube** as part of each segment body.
- Designs the **integrated drip tray** for overflow capture.
- Ensures the outer segment body is **clean between pockets** — no accessory
  notches, grip textures, or external alignment features. Planting pocket
  protrusions are expected and integral to the design.
- Makes trade-off decisions (e.g., pocket angle vs. printability).
- Writes the master `build_tower.py` and component scripts for Blender (`bpy`).
- Saves `.blend` files to `exports/blend/` for GUI debugging.
- Outputs: STL files, .blend files, parameter configs.

### 4.2 Engineering Agent

**Responsibility**: Structural integrity, water flow, and mechanical validation.

- Analyzes wall thickness, overhang angles, bridging distances.
- Validates interlock strength (basic FEA reasoning or geometric analysis).
- Ensures water channels have correct slope (minimum 2° grade).
- Checks pocket drainage paths for dead zones.
- Runs `trimesh` watertight checks on exported STLs.
- Outputs: Validation reports, issue lists, fix recommendations.

### 4.3 Print Agent

**Responsibility**: 3D printing feasibility and optimization.

- Validates all parts fit within build volume.
- Checks for support-free printability (overhang analysis).
- Estimates print time and material usage.
- Suggests orientation changes if needed.
- Generates recommended slicer profiles / settings.
- Outputs: Print feasibility reports, slicer configs.

### 4.4 Aesthetics Agent

**Responsibility**: Visual design quality and elegance.

- Evaluates whether the golden-angle spiral is visually apparent.
- Suggests fillet radii, chamfers, and organic curves.
- Reviews proportions (segment height vs. width, pocket size vs. body).
- Ensures the assembled tower looks cohesive and sculptural.
- Checks that interlock seams are visually minimal.
- Outputs: Aesthetic review, suggested refinements.

### 4.5 Integration & Test Agent

**Responsibility**: End-to-end validation and iteration orchestration.

- Runs the full test suite (`pytest`) after each iteration.
- Validates BOM completeness (all off-the-shelf parts specified).
- Checks that all agents' outputs are consistent.
- Maintains the iteration log (`CHANGELOG.md`).
- **Decides** whether to iterate or promote to "Ready for Human Evaluation."
- Outputs: Test results, iteration decision, final deliverables package.

---

## 5. File Structure

```
golden-tower/
├── .copilot-instructions.md     ← This file
├── AGENTS.md                    ← Swarm orchestration config
├── CHANGELOG.md                 ← Auto-maintained iteration log
├── README.md                    ← Project overview & assembly guide
├── tower_params.py              ← All parametric dimensions (single source of truth)
├── build_tower.py               ← Main Blender build script (run with blender --background --python)
├── validate_visual.py           ← Blender headless render + cross-section + analysis pipeline
├── components/
│   ├── segment.py               ← Standard segment (pockets + integrated tube + drip tray)
│   ├── top_cap.py               ← Top cap / water deflector
│   ├── bottom_segment.py        ← Bottom segment with QD fitting
│   └── interlock.py             ← Interlock mechanism geometry
├── tests/
│   ├── test_geometry.py         ← Golden angle validation
│   ├── test_printability.py     ← Build volume, overhangs, wall thickness
│   ├── test_watertight.py       ← Mesh integrity checks
│   ├── test_interlock.py        ← Fit tolerance and alignment
│   └── test_assembly.py         ← Full tower stack validation
├── exports/
│   ├── stl/                     ← STL files per component
│   ├── blend/                   ← Blender .blend files for GUI inspection
│   └── renders/                 ← Rendered PNGs (multi-view, cross-sections)
├── reports/
│   ├── engineering_review.md
│   ├── print_feasibility.md
│   ├── aesthetic_review.md
│   └── iteration_summary.md
└── slicer/
    └── profiles/                ← Slicer config files
```

---

## 6. Iteration Protocol

### 6.1 Iteration Cycle

```
┌─────────────────────────────────────────────────────────────┐
│  1. Architect designs / modifies parametric model        │
│  2. Run visual validation: python validate_visual.py     │
│  3. Engineering validates structure & water flow          │
│  4. Print agent validates manufacturability               │
│  5. Aesthetics agent reviews RENDER IMAGES (not code)     │
│  6. Integration agent runs full test suite                │
│  7. Write iteration summary + score                      │
│  8. Commit, push, then STOP for human review             │
│  9. Human says GO → continue | NO-GO → address feedback  │
│ 10. Decision: ITERATE (go to 1) or PROMOTE               │
└─────────────────────────────────────────────────────────────┘
```

### 6.1.1 Visual Validation (MANDATORY)

After every geometry change, the orchestrator MUST run:
```bash
blender --background --python validate_visual.py
```

This uses Blender's EEVEE renderer to generate in `exports/renders/`:
- **`{name}_front.png`** — Front view render (XZ plane)
- **`{name}_right.png`** — Right side view render (YZ plane)
- **`{name}_top.png`** — Top-down view render (XY plane)
- **`{name}_perspective.png`** — 3/4 isometric view with materials
- **`{name}_cross_{z}mm.png`** — Cross-section renders at key Z-heights
  using `bpy.ops.mesh.bisect` to slice the mesh in-place
- **`{name}_analysis.txt`** — BMesh-based dimensional analysis (volume,
  manifold status, bounding box, wall thickness sampling)

Because these are **real 3D renders** (not matplotlib wireframes), agents
can evaluate actual surface quality, pocket depth, material transitions,
and visual proportions. The orchestrator and all reviewing agents MUST
examine these images before scoring.

**Do not score aesthetics, printability, or water flow without looking at
the renders.** If you cannot see the renders, say so — do not invent scores.

### 6.1.2 Human-in-the-Loop Gate (MANDATORY)

After committing and pushing each iteration, the orchestrator MUST:
1. Present a summary of what changed, the current scores, and any open issues.
2. List the render files generated in `exports/renders/`.
3. **STOP and ask the human**: "Iteration N complete. Renders are in
   exports/renders/. Please review and reply GO to continue or provide
   feedback."
4. **Wait for human response** before starting the next iteration.

This is not optional. The swarm does NOT continue autonomously between
iterations. Each iteration requires explicit human approval.

### 6.2 Iteration Rules

1. **Maximum iterations**: 12 per design cycle. If not converging, write a
   summary of unresolved issues and promote for human input.
2. **Each iteration must improve** at least one metric without regressing
   others. If a trade-off is required, document it in the changelog.
3. **No agent may override** another agent's domain without documenting
   the rationale.
4. **All geometry changes** must be made in the parametric model
   (`tower_params.py` + component scripts run via Blender), never by
   manual STL editing. Always save .blend files alongside STLs.
5. **Every iteration** produces a git commit with a descriptive message
   and is **pushed to GitHub** (`git push origin main`).

### 6.3 Scoring Rubric (0–10 per category)

| Category | Weight | Criteria |
|---|---|---|
| **Golden Angle Accuracy** | 20% | Nodes at exactly 137.508° apart; parastichy visible |
| **Printability** | 20% | No supports needed; fits build volume; watertight mesh |
| **Water Flow** | 20% | Complete flow path; no dead zones; proper drainage |
| **Structural Integrity** | 15% | Interlock holds; wall thickness adequate; stable when stacked |
| **Aesthetics** | 15% | Elegant curves; minimal seams; visually striking spiral |
| **Assembly Ease** | 10% | Tool-free; intuitive; cannot be assembled wrong |

**Promotion threshold**: Weighted score ≥ **7.5 / 10** with no category below 6.

---

## 7. Ready for Human Evaluation — Deliverables

When the Integration Agent promotes a design, the following must exist:

- [ ] All STL files in `exports/stl/` (one per printable component)
- [ ] All .blend files in `exports/blend/` (for GUI inspection and further work)
- [ ] `README.md` with assembly instructions and BOM
- [ ] `CHANGELOG.md` with full iteration history
- [ ] All reports in `reports/` filled out
- [ ] `tower_params.py` fully commented with every dimension explained
- [ ] Test suite passing: `pytest tests/ -v` all green
- [ ] Final weighted score documented in `reports/iteration_summary.md`
- [ ] Git tagged as `v{iteration}-ready-for-review` and pushed to GitHub
- [ ] All changes pushed to `origin/main`

---

## 8. Parametric Defaults

```python
# tower_params.py — starting values (all dimensions in mm)
GOLDEN_ANGLE = 137.50776405003785  # degrees (exact: 360 / φ²)

# Segment — pockets spiral UPWARD within each segment
NODES_PER_SEGMENT = 3
SEGMENT_HEIGHT = 200.0        # mm — tall enough for visible upward spiral
SEGMENT_OUTER_DIAMETER = 160.0  # mm — max outer envelope
SUPPLY_TUBE_OD = 32.0        # mm — integrated supply tube outer diameter
SUPPLY_TUBE_ID = 28.0        # mm — integrated supply tube inner diameter
WALL_THICKNESS = 2.0           # mm — minimum wall thickness
OUTER_BODY_STYLE = "clean"    # no accessory notches on exterior

# Planting Pocket
POCKET_DIAMETER = 52.0         # mm — for 2" net cup with clearance
POCKET_TILT_ANGLE = 20.0       # degrees from vertical
POCKET_DEPTH = 45.0            # mm

# Interlock
INTERLOCK_HEIGHT = 10.0        # mm — engagement depth
INTERLOCK_CLEARANCE = 0.3      # mm — printer tolerance gap
INTERLOCK_ROTATION = (NODES_PER_SEGMENT * GOLDEN_ANGLE) % 360  # 52.524°

# Water Flow
CHANNEL_WIDTH = 8.0            # mm
CHANNEL_DEPTH = 3.0            # mm
CHANNEL_SLOPE = 3.0            # degrees minimum grade

# Top Cap
CAP_DEFLECTOR_ANGLE = 30.0     # degrees — cone half-angle
CAP_OVERHANG = 10.0            # mm — beyond outer diameter

# Bottom Segment
QD_FITTING_ID = 10.0           # mm — 3/8" barb inner bore
LID_ATTACHMENT_TYPE = "bayonet"  # or "threaded"
LID_THREAD_PITCH = 3.0         # mm (if threaded)

# Print
BUILD_VOLUME = (256, 256, 256)  # mm — target printer
LAYER_HEIGHT = 0.2              # mm
NOZZLE_DIAMETER = 0.4           # mm
```

---

## 9. Key Design Patterns for Blender (bpy)

```python
# Golden angle node placement pattern — used by all component scripts
import math
import sys
import os

# tower_params.py must be importable
sys.path.insert(0, os.path.dirname(os.path.abspath(__file__)))

GOLDEN_ANGLE_RAD = math.radians(137.50776405003785)

def place_nodes(n_nodes, radius, segment_height):
    """Generate (x, y, z, angle) positions for n nodes following golden angle.
    
    CRITICAL: Each node is at a DIFFERENT height within the segment.
    The vertical pitch = segment_height / n_nodes. This creates the
    upward spiral — not a flat ring of pockets.
    """
    vertical_pitch = segment_height / n_nodes
    positions = []
    for i in range(n_nodes):
        angle = i * GOLDEN_ANGLE_RAD
        z = i * vertical_pitch  # each pocket at a different height!
        x = radius * math.cos(angle)
        y = radius * math.sin(angle)
        positions.append((x, y, z, math.degrees(angle)))
    return positions

# Full tower: node positions across all segments
def place_all_nodes(n_segments, nodes_per_seg, radius, segment_height):
    """Place all nodes across all segments, maintaining continuous helix."""
    all_pos = []
    for seg in range(n_segments):
        seg_offset_z = seg * segment_height
        for i in range(nodes_per_seg):
            global_idx = seg * nodes_per_seg + i
            angle = global_idx * GOLDEN_ANGLE_RAD
            z = seg_offset_z + i * (segment_height / nodes_per_seg)
            x = radius * math.cos(angle)
            y = radius * math.sin(angle)
            all_pos.append((x, y, z, math.degrees(angle), seg, i))
    return all_pos
```

### 9.1 Blender Component Script Pattern

Every component script follows this structure:
```python
#!/usr/bin/env python3
"""
Component Name — Golden Tower
Run: blender --background --python components/component_name.py
"""
import bpy
import bmesh
import math
import os
import sys

# Import tower_params (standalone Python — not bpy-dependent)
sys.path.insert(0, os.path.join(os.path.dirname(os.path.abspath(__file__)), '..'))
from tower_params import *

def clear_scene():
    """Remove all objects from the default scene."""
    bpy.ops.object.select_all(action='SELECT')
    bpy.ops.object.delete()

def build_component():
    """Build the component geometry using bpy/bmesh."""
    clear_scene()
    
    # ... geometry construction using bmesh or bpy.ops.mesh ...
    
    # Apply modifiers, clean up
    bpy.ops.object.select_all(action='SELECT')
    return bpy.context.selected_objects[0]

def export(obj, name):
    """Export to STL and save .blend file."""
    stl_dir = os.path.join(os.path.dirname(__file__), '..', 'exports', 'stl')
    blend_dir = os.path.join(os.path.dirname(__file__), '..', 'exports', 'blend')
    os.makedirs(stl_dir, exist_ok=True)
    os.makedirs(blend_dir, exist_ok=True)
    
    # Select only this object
    bpy.ops.object.select_all(action='DESELECT')
    obj.select_set(True)
    bpy.context.view_layer.objects.active = obj
    
    # Export STL
    stl_path = os.path.join(stl_dir, f'{name}.stl')
    bpy.ops.wm.stl_export(filepath=stl_path, export_selected_objects=True)
    
    # Save .blend
    blend_path = os.path.join(blend_dir, f'{name}.blend')
    bpy.ops.wm.save_as_mainfile(filepath=blend_path)
    
    print(f'Exported: {stl_path}')
    print(f'Saved:    {blend_path}')

if __name__ == '__main__':
    obj = build_component()
    export(obj, 'component_name')
```

### 9.2 Boolean Operations in Blender

```python
# Blender boolean pattern — more debuggable than build123d
def boolean_op(target_obj, tool_obj, operation='DIFFERENCE'):
    """Apply a boolean modifier and delete the tool object.
    
    Operations: 'DIFFERENCE', 'UNION', 'INTERSECT'
    """
    mod = target_obj.modifiers.new(name='Boolean', type='BOOLEAN')
    mod.operation = operation
    mod.object = tool_obj
    mod.solver = 'EXACT'  # more reliable than 'FAST'
    
    bpy.context.view_layer.objects.active = target_obj
    bpy.ops.object.modifier_apply(modifier=mod.name)
    
    # Remove tool object
    bpy.data.objects.remove(tool_obj, do_unlink=True)
```

### 9.3 Cross-Section Visualization

```python
# Slice a mesh at height Z using bpy.ops.mesh.bisect
def cross_section_at_z(obj, z_height):
    """Duplicate object and bisect at z_height for cross-section view."""
    # Duplicate
    bpy.ops.object.select_all(action='DESELECT')
    obj.select_set(True)
    bpy.ops.object.duplicate()
    section = bpy.context.active_object
    
    # Enter edit mode and bisect
    bpy.ops.object.mode_set(mode='EDIT')
    bpy.ops.mesh.select_all(action='SELECT')
    bpy.ops.mesh.bisect(
        plane_co=(0, 0, z_height),
        plane_no=(0, 0, 1),
        clear_inner=True,   # remove below
        clear_outer=False,   # keep above
    )
    bpy.ops.object.mode_set(mode='OBJECT')
    return section
```

### 9.4 Headless Rendering Pattern

```python
def setup_render_scene(obj, camera_location, camera_target=(0, 0, 100)):
    """Set up camera, lights, and render settings for headless EEVEE render."""
    scene = bpy.context.scene
    scene.render.engine = 'BLENDER_EEVEE'
    scene.render.resolution_x = 1200
    scene.render.resolution_y = 900
    scene.render.image_settings.file_format = 'PNG'
    
    # Camera
    bpy.ops.object.camera_add(location=camera_location)
    cam = bpy.context.active_object
    # Point camera at target
    direction = mathutils.Vector(camera_target) - mathutils.Vector(camera_location)
    cam.rotation_euler = direction.to_track_quat('-Z', 'Y').to_euler()
    scene.camera = cam
    
    # Sun light
    bpy.ops.object.light_add(type='SUN', location=(200, -200, 400))
    light = bpy.context.active_object
    light.data.energy = 3.0
    
    # Material on object (if none)
    if not obj.data.materials:
        mat = bpy.data.materials.new('TowerMaterial')
        mat.use_nodes = True
        bsdf = mat.node_tree.nodes['Principled BSDF']
        bsdf.inputs['Base Color'].default_value = (0.29, 0.56, 0.85, 1.0)
        bsdf.inputs['Roughness'].default_value = 0.4
        obj.data.materials.append(mat)

def render_to_file(filepath):
    """Render the current scene to a PNG file."""
    bpy.context.scene.render.filepath = filepath
    bpy.ops.render.render(write_still=True)
    print(f'Rendered: {filepath}')
```

---

## 10. Quality Gates (Automated Tests)

### test_geometry.py
- Assert angular offset between consecutive nodes == 137.508° ± 0.01°
- Assert segment-to-segment rotation == 52.524° ± 0.01°
- Assert parastichy count matches Fibonacci pair (3, 5) or (5, 8)

### test_printability.py
- Assert all parts fit within BUILD_VOLUME
- Assert minimum wall thickness ≥ 1.6 mm everywhere
- Assert maximum overhang angle ≤ 55°
- Assert maximum bridge span ≤ 40 mm
- Assert mesh is manifold and watertight (trimesh)

### test_watertight.py
- Assert all water-contact surfaces are closed meshes
- Assert channel connectivity from top cap to bottom drain

### test_interlock.py
- Assert male/female geometry overlap == 0 at INTERLOCK_CLEARANCE
- Assert rotation lock angle matches INTERLOCK_ROTATION
- Assert segments cannot assemble at wrong angle (interference check)

### test_assembly.py
- Assert N segments stack to expected total height
- Assert all pockets are accessible (no collision with adjacent segments)
- Assert integrated supply tube sections align across segment joints
- Assert nodes spiral upward (each successive node has greater Z)
- Assert segment height:width ratio ≥ 1.0

---

## 11. Error Handling & Recovery

- If a Blender boolean fails → switch solver from 'EXACT' to 'FAST' or
  vice versa; add slight offsets to avoid co-planar faces; check normals
  are consistent (`bpy.ops.mesh.normals_make_consistent()`); save the
  .blend file for manual debugging and log the error.
- If a mesh fails manifold check → use BMesh to find non-manifold edges
  (`[e for e in bm.edges if not e.is_manifold]`); fill holes with
  `bpy.ops.mesh.fill()`; re-export and re-test.
- If part exceeds build volume → reduce SEGMENT_HEIGHT or
  SEGMENT_OUTER_DIAMETER; document the change.
- If interlock is too tight/loose → adjust INTERLOCK_CLEARANCE in 0.05 mm
  increments.
- If aesthetic score is low → add bevel modifiers (min width 2 mm), smooth
  transitions, and subdivision surface for organic curves at pocket openings.
- If Blender crashes in headless mode → check `blender --debug --background
  --python script.py` for detailed error output; reduce mesh complexity or
  boolean count; break complex operations into sequential steps.

---

## 12. Communication Protocol Between Agents

Agents communicate through **files in the repository**:

- Design changes → commit to git with `[architect]` prefix and push to GitHub
- Reviews → write to `reports/` with `[engineering]`, `[print]`, `[aesthetics]` prefix
- Issues → create entries in `reports/iteration_summary.md` with severity:
  - **BLOCKER**: Must fix before promotion (score < 6 in any category)
  - **MAJOR**: Should fix; affects score significantly
  - **MINOR**: Nice to have; cosmetic or optimization
- Decisions → Integration agent writes `DECISION:` entries to changelog

---

## 13. Glossary

| Term | Definition |
|---|---|
| **Golden angle** | 137.508°; the angle that produces the most uniform distribution of points around a circle |
| **Parastichy** | Visible spiral pattern in phyllotactic arrangements; count follows Fibonacci sequence |
| **Net cup** | Slotted plastic cup used in hydroponics to hold growing medium and plant roots |
| **NFT** | Nutrient Film Technique — thin film of nutrient solution flows over roots |
| **Drip tray / catch plate** | Integrated basin within each segment that collects overflow nutrient solution and channels it downward |
| **Integrated supply tube** | Central water supply tube built into each segment as part of the printed body (not a separate component) |
| **Quick-disconnect (QD)** | Tool-free hose coupling with shut-off valve |
| **build123d** | ~~Former CAD kernel — replaced by Blender in iteration 4~~ |
| **Blender (bpy)** | Python-scriptable 3D modeling, rendering, and mesh analysis application |
| **BMesh** | Blender's low-level mesh editing API for programmatic geometry construction |
| **EEVEE** | Blender's real-time render engine — used for fast headless validation renders |
| **Manifold mesh** | A 3D mesh with no holes, self-intersections, or non-manifold edges — required for 3D printing |

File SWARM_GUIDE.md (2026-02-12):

# How to Launch the Golden Tower Agent Swarm

## Swarm Entry Prompt

When entering Claude swarm mode, use this prompt:

---

```
You are the orchestrator of a human-in-the-loop design shop building the
"Golden Tower" — a modular, 3D-printable hydroponic grow tower where planting
pockets spiral upward following the golden angle (137.508°). After each iteration
you MUST pause and present results for human review before continuing.

Read these files IN ORDER before doing anything else:
1. .copilot-instructions.md — Full product spec, constraints, and protocols
2. AGENTS.md — Agent roles, handoff protocol, and iteration flow
3. tower_params.py — Current parametric dimensions (single source of truth)
4. CHANGELOG.md — Iteration history and current state
5. reports/iteration_summary.md — Current scores and open issues

You have 5 agents: orchestrator (you), architect, engineer, printer, aesthetician.

KEY DESIGN DECISIONS already made — do not revisit:
- The central supply tube is INTEGRATED into each segment (no separate tube part)
- Each segment has an INTEGRATED drip tray / catch plate for overflow
- The 3 pockets per segment spiral UPWARD at different heights (not a flat ring)
- Segment height:width ratio ≥ 1.0 (currently 1.25) for visible upward sweep
- The outer body between pockets is CLEAN — no accessory notches or grip features
- Pocket protrusions extending beyond the outer cylinder are expected and integral
- The architect has hydroponic systems expertise (NFT, root zone, drainage, etc.)

Begin Iteration 1: hand off to the architect to generate the first complete
parametric geometry for all components (standard segment with integrated tube
and drip tray, top cap, bottom segment with QD fitting, interlock mechanism)
using build123d. The architect should study the reference STL
(3-Way_Planting_Module_custom.stl) to understand the integrated tube and drip
tray geometry before designing.

After geometry exists, run visual validation (`python validate_visual.py`) to
generate render PNGs and cross-section analysis in `exports/renders/`. Then run
the engineering, print, and aesthetic reviews in parallel — all reviewing agents
MUST examine the rendered images before scoring. Do not score aesthetics,
printability, or water flow without looking at the renders.

After scoring, commit and push to GitHub. Then STOP and present results to the
human: what changed, current scores, open issues, and the render files in
`exports/renders/`. Ask the human to reply GO or provide feedback.

**Do not start the next iteration until the human responds.** This is not
autonomous — each iteration requires explicit human approval. Iterate until the
weighted score reaches 7.5/10 with no category below 6, or until you hit 12
iterations.

The workspace is at /home/tmr/src/learn/golden-tower/ with build123d installed
in ./venv/. Run `source venv/bin/activate` before any Python commands.
The GitHub repo is https://github.com/terry-richards/golden-tower (remote: origin).
```

---

## How the Instructions Are Structured (Design Rationale)

### Layered information architecture

The instructions use a **top-down** structure that mirrors how an agent (or a
new engineer) would onboard:

| Layer | File | Purpose |
|---|---|---|
| **Mission** | `.copilot-instructions.md` §1 | Why we exist — one paragraph |
| **What to build** | `.copilot-instructions.md` §2 | Product spec with exact numbers |
| **How to build it** | `.copilot-instructions.md` §3, §9 | Tech stack and code patterns |
| **Who does what** | `AGENTS.md` | Role definitions with clear boundaries |
| **How to iterate** | `.copilot-instructions.md` §6 | Cycle, rules, scoring rubric |
| **When to stop** | `.copilot-instructions.md` §7 | Promotion criteria and deliverables |
| **Current state** | `CHANGELOG.md`, `reports/` | Living documents updated each iteration |

### Why this structure works for agent swarms

1. **Single source of truth**: `tower_params.py` is the only place dimensions
   live. Agents can't drift out of sync because they all import from one file.

2. **Explicit scoring rubric**: Agents need unambiguous success criteria. The
   weighted rubric (§6.3) with a hard promotion threshold (7.5/10, no category
   below 6) gives the orchestrator a mechanical decision process — no judgment
   calls needed.

3. **File-based communication**: Agents communicate through the repository, not
   through conversation. This makes the state inspectable, versionable, and
   recoverable if any agent fails mid-iteration.

4. **Bounded autonomy**: Maximum 12 iterations prevents runaway loops. Each
   agent has a clear scope (architect doesn't review prints; printer doesn't
   redesign geometry). The orchestrator is the only one that makes cross-cutting
   decisions.

5. **Automated quality gates**: The pytest test suite catches parametric
   violations immediately. An agent can't break the golden angle or exceed the
   build volume without tests failing.

6. **Stub architecture**: Every component file exists with `NotImplementedError`
   stubs. The architect knows exactly what functions to implement and what the
   expected interface is. No ambiguity about file locations or function signatures.

### Key prompt engineering patterns used

- **Persona + scope**: Each agent instruction starts with "You are the X Agent"
  and explicitly lists responsibilities and non-responsibilities.
- **Concrete over abstract**: Instead of "make it printable," the instructions
  say "overhangs ≤ 55° from vertical, bridges ≤ 40mm."
- **Severity taxonomy**: BLOCKER / MAJOR / MINOR gives agents a shared language
  for prioritization without requiring nuanced judgment.
- **Exit conditions**: "Score ≥ 7.5 with no category below 6" is a bright line,
  not a fuzzy guideline.
- **Recovery procedures**: §11 tells agents what to do when things break,
  rather than leaving them stuck.

## Tips for Running the Swarm

1. **Repo is ready**: The repo is initialized and connected to GitHub at
   https://github.com/terry-richards/golden-tower. The swarm pushes
   after every iteration commit: `git push origin main`.

2. **Review renders after each iteration**: The swarm will pause after each
   iteration and ask for GO/NO-GO. Look at the PNG files in `exports/renders/`
   — these show orthographic views and cross-sections. This is your primary
   mechanism for catching design errors early.

3. **Monitor the changelog**: `CHANGELOG.md` is the human-readable audit trail.
   Check it to see what the swarm decided at each iteration.

4. **Intervene via reports**: If you want to nudge the swarm, edit
   `reports/iteration_summary.md` and add a BLOCKER issue. The orchestrator
   will route it to the appropriate agent.

5. **Adjust parameters**: If the swarm converges on something you don't like,
   modify `tower_params.py` directly and reset the iteration counter.

6. **Scale up**: To add more agents (e.g., a "botanist" that optimizes pocket
   angles for specific plants), add a new section to `AGENTS.md` and reference
   it from the orchestrator's handoff list.

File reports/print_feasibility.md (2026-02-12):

# [Print] Print Feasibility Report -- Golden Tower Iteration 1

## Status: REVIEWED

**Reviewer**: Print Agent
**Iteration**: 1 (initial geometry)
**Date**: 2026-02-12
**Target Printer**: Bambu Lab P1S (256 x 256 x 256 mm, enclosed)
**Target Material**: PETG or ASA
**Files reviewed**: `tower_params.py`, `components/segment.py`, `components/top_cap.py`, `components/bottom_segment.py`, `exports/stl/*.stl`

---

## [Print] 1. Build Volume Fit

**Build volume**: 256 x 256 x 256 mm (Bambu Lab P1S)

### 1.1 Bounding Box Derivation

All bounding dimensions were derived analytically from the parametric source
code in `tower_params.py` and the component build scripts. Key inputs:

- `SEGMENT_OUTER_RADIUS` = 80 mm (body diameter 160 mm)
- `POCKET_RADIAL_OFFSET` = 50 mm (pocket center from tower axis)
- `POCKET_TILT_ANGLE` = 20 deg
- `POCKET_SOLID_LENGTH` = 95 mm (45 mm depth + 50 mm overlap extension)
- `POCKET_RADIUS` + `WALL_THICKNESS` = 26 + 2 = 28 mm (pocket exterior radius)
- `SEGMENT_HEIGHT` = 200 mm, `INTERLOCK_HEIGHT` = 10 mm

The pocket protrusion maximum radial extent from tower axis:

```
R_max = POCKET_RADIAL_OFFSET
      + (POCKET_SOLID_LENGTH / 2) * sin(POCKET_TILT_ANGLE)
      + (POCKET_RADIUS + WALL_THICKNESS) * cos(POCKET_TILT_ANGLE)
      = 50 + 47.5 * sin(20 deg) + 28 * cos(20 deg)
      = 50 + 16.25 + 26.32
      = 92.57 mm from center
```

Pocket 0 (azimuth 0 deg) extends primarily along +X. Pocket 1 (azimuth
137.5 deg) extends into -X/+Y quadrant. Pocket 2 (azimuth 275 deg) extends
into +X/-Y quadrant. The axis-aligned bounding box depends on the projection
of these tilted cylinders onto the coordinate axes.

Vertical extent computation -- the lowest pocket (pocket 0) protrusion extends
below z=0:

```
POCKET_Z_OFFSET = INTERLOCK_HEIGHT + (POCKET_DEPTH/2) * cos(20 deg) + 2.0
               = 10 + 22.5 * 0.940 + 2.0
               = 33.14 mm

Pocket 0 center: z = 33.14 mm
Lower Z extent: 33.14 - 47.5 * cos(20 deg) - 28 * sin(20 deg)
             = 33.14 - 44.65 - 9.58
             = -21.1 mm

Pocket 2 (highest) center: z = 33.14 + 2 * 66.67 = 166.48 mm
Upper Z extent: 166.48 + 47.5 * cos(20 deg) + 28 * sin(20 deg)
             = 166.48 + 44.65 + 9.58
             = 220.7 mm (vs. male interlock top at 210 mm)
```

Total Z extent: approximately 220.7 - (-21.1) = **241.8 mm**

### 1.2 Component Fit Summary

| Component | Bounding Box (mm) | X Margin | Y Margin | Z Margin | Fits? |
|---|---|---|---|---|---|
| Standard Segment | ~172.5 x 160.3 x 241.8 | 83.5 mm | 95.7 mm | **14.2 mm** | YES |
| Bottom Segment | ~172.5 x 160.3 x 241.8 | 83.5 mm | 95.7 mm | **14.2 mm** | YES |
| Top Cap | ~180.0 x 180.0 x 58.0 | 76.0 mm | 76.0 mm | 198.0 mm | YES |

**Notes on Bottom Segment**: The QD barb extends to z = -20 mm and the
reservoir lid ring to z = -10 mm. However, the lowest pocket protrusion
already extends to z = -21.1 mm, so the bottom-mounted features do not
increase the bounding box beyond the standard segment. The bottom segment
has no female interlock bore but otherwise shares identical pocket placement,
resulting in the same Z envelope.

**Notes on Top Cap**: The bounding box spans from z = -10 mm (interlock socket
base) to z = 48 mm (finial dome apex), giving 58 mm total height. The base
plate extends to r = 90 mm (180 mm diameter), which is the widest X/Y extent.

### 1.3 Build Volume Verdict

All three components fit within the 256 x 256 x 256 mm build volume. The
**Z margin of 14.2 mm (5.5%) is tight** for both segment variants. PETG and
ASA are prone to thermal warping on tall prints, and any upward warping at the
top layers could bring the nozzle into conflict with previously deposited
material or trigger Z-limit errors.

The **P1S's enclosed build chamber** mitigates thermal warping significantly,
but the margin remains a concern. Any design changes that increase the segment
Z envelope by more than 14 mm will **exceed the build volume**.

**Risk level**: MINOR -- printable but with thin tolerances that must be
monitored.

---

## [Print] 2. Overhang Analysis

**Maximum permitted overhang**: 55 deg from vertical (`MAX_OVERHANG_ANGLE`
in `tower_params.py`)

### 2.1 Pocket Cylinder Exterior Surface

A cylinder of radius 28 mm tilted 20 deg from vertical has surface normals
that rotate with the tilt. The most extreme downward-facing surface normal on
the pocket underside:

- Pocket axis direction: tilted 20 deg from +Z toward the radial outward
  direction
- Most downward-facing surface normal on the cylinder: perpendicular to the
  tilted axis, pointing toward -Z
- This normal has Z-component: -sin(20 deg) = -0.342
- Angle from +Z: arccos(-0.342) = 110 deg
- **Overhang from vertical**: 110 - 90 = **20 deg**

20 deg < 55 deg limit. **The pocket exterior undersides are within the safe
overhang zone.** No supports needed for the outside of the pocket protrusions.

### 2.2 Pocket Interior -- Closed Bottom Face (CRITICAL)

Each pocket bore (52 mm diameter, 43 mm deep) is capped at the inner end by a
solid disk (the pocket bottom, `WALL_THICKNESS` = 2 mm thick). This disk is
perpendicular to the pocket axis, which is tilted 20 deg from vertical. The
outward normal of this face points inward toward the tower center and
predominantly downward:

```
Normal direction: (-sin(20 deg) * cos(azimuth),
                   -sin(20 deg) * sin(azimuth),
                   -cos(20 deg))
Z component: -cos(20 deg) = -0.940
Angle from +Z: arccos(-0.940) = 160 deg
Overhang from vertical: 160 - 90 = 70 deg
```

**70 deg >> 55 deg limit.** The pocket bottom face has a severe overhang that
requires support material inside the pocket bore. This support would be
deposited inside a 52 mm diameter cylinder tilted at 20 deg -- **removal would
be extremely difficult**, especially for the two upper pockets which are less
accessible.

This affects **3 pockets per segment x 8 segments = 24 pocket interiors**
across the full tower.

### 2.3 Male Interlock Ring Step (CRITICAL)

The male interlock ring (radius 29 mm) protrudes above the body cylinder
(radius 80 mm) at z = 200-210 mm. This creates a horizontal step (90 deg
overhang) at the body top face. The unsupported horizontal span:

```
Step span = SEGMENT_OUTER_RADIUS - MALE_INTERLOCK_RADIUS
          = 80 - 29
          = 51 mm
```

This is a **51 mm horizontal overhang** at 90 deg from vertical, exceeding
both the 55 deg overhang limit and the 40 mm bridge span limit.

### 2.4 Top Cap Cone Interior

The inner surface of the hollow deflector cone narrows from r = 77.6 mm to
r = 2.6 mm over 38 mm of height. The inner surface slope:

```
arctan((77.6 - 2.6) / 38) = arctan(1.974) = 63.1 deg from vertical
```

At 63 deg from vertical, this technically exceeds the 55 deg limit. In
practice, at 0.2 mm layer height each layer steps inward by
0.2 * tan(63.1 deg) = 0.39 mm, which is within one nozzle width (0.4 mm).
The P1S should print this acceptably with moderate cooling but will produce
a rough inner surface. Functionally acceptable for a water deflector.

### 2.5 Female Interlock Socket Ceiling

The female interlock bore (annular groove from r = 16 mm to r = 29.3 mm,
z = 0 to z = 10 mm) has a horizontal ceiling at z = 10 mm:

```
Bridge span = FEMALE_INTERLOCK_RADIUS - SUPPLY_TUBE_OD / 2
            = 29.3 - 16.0
            = 13.3 mm
```

This is a circular bridge at 13.3 mm span, well under the 40 mm limit. The
annular (circular) bridge geometry is favorable as bridging filament is laid
tangentially. Self-supporting with standard bridge settings.

### 2.6 Overhang Summary Table

| Feature | Overhang Angle | Limit | Span | Status |
|---|---|---|---|---|
| Pocket exterior (underside) | 20 deg | 55 deg | -- | **PASS** |
| Pocket interior (bottom face) | **70 deg** | 55 deg | ~52 mm dia | **FAIL** |
| Male interlock ring step | **90 deg** | 55 deg | 51 mm | **FAIL** |
| Top cap inner cone | 63 deg | 55 deg | gradual | MARGINAL |
| Female interlock ceiling | 90 deg | -- | 13.3 mm bridge | **PASS** (bridge) |
| Finial dome (8 mm hemisphere) | up to 90 deg | 55 deg | 16 mm dia | **PASS** (tiny) |
| QD barb ridges | ~45 deg cones | 55 deg | -- | **PASS** |

---

## [Print] 3. Support Requirements

### 3.1 Features Requiring Support

| # | Component | Feature | Support Type | Removal Difficulty |
|---|---|---|---|---|
| S1 | Segment / Bottom | Pocket interior bottom face (x3 per segment) | Tree/linear inside 52 mm tilted bore | **HARD** -- deep inside a narrow tilted bore; risk of damaging 2 mm pocket walls during removal |
| S2 | Segment / Bottom | Male interlock ring step (51 mm overhang) | Full support plate under body top face, r = 29-80 mm | **MODERATE** -- accessible from open female socket below; large contact area to break away |
| S3 | Top Cap | Inner cone surface (partial) | Thin supports inside hollow cone | **MODERATE** -- accessible from the open bottom of the cone |

### 3.2 Self-Supporting Redesign Opportunities

**S1 -- Pocket bottom face (HIGH PRIORITY, RECOMMENDED)**:

Replace the flat pocket bottom with a **conical or domed interior**. A 45 deg
internal cone at the pocket bottom would reduce the maximum overhang from
70 deg to approximately 70 - 45 = 25 deg (well within limit). The net cup
sits at the pocket mouth and does not interact with the bottom geometry, so
this change has zero functional impact on planting.

Alternatively, **make the pocket a through-hole** (open at both ends). The
inner end connects to the hollow tower interior. This eliminates the bottom
face entirely, removes the overhang, AND creates a natural drain path for
each pocket. However, this changes the water containment strategy and must be
coordinated with the Engineering Agent.

**S2 -- Male interlock ring step (HIGH PRIORITY, RECOMMENDED)**:

Add a **45-50 deg chamfer or taper** transitioning from the body outer wall
(r = 80 mm) down to the interlock ring (r = 29 mm). A linear taper over
approximately 51 mm of height at 45 deg creates a self-supporting slope.
This transition is **inside the hollow body** and does not change the external
silhouette. Design options:

- 45 deg taper: 51 mm height, cone from r=80 down to r=29 at t=200 mm
- 50 deg taper: ~43 mm height (steeper but still within limit)
- This is already identified as priority P1 in the iteration summary

**S3 -- Top cap inner cone (LOW PRIORITY)**:

Increase `CAP_HEIGHT` or narrow the cone base to steepen the inner surface
below 55 deg. Alternatively, accept the slightly rough inner surface since it
is not visible in normal use and serves only as a water deflector.

### 3.3 Support Material Estimate (if NOT redesigned)

If supports are required:

- Per segment: 3 pocket bore supports + 1 interlock step support
- Pocket bore support: approximately 5-8 g each (small volume inside bore)
- Interlock step support: approximately 20-30 g (large annular area)
- Total per segment: approximately 35-55 g of support material (wasted)
- Full tower (8 segments): approximately 280-440 g of wasted support

**Strong recommendation**: Redesign S1 and S2 to be self-supporting before
printing. The combined savings: approximately 300+ g of material, 2-3 hours
of print time per segment, and elimination of the most difficult post-
processing step (support removal inside pocket bores).

---

## [Print] 4. Material Estimate

### 4.1 Method

Material volumes estimated analytically from parametric geometry. The design
is predominantly thin-walled (2.0 mm general walls, 2.4 mm water-contact
walls), so most structure consists of 100% solid perimeters with no infill.
The 15% infill setting applies only to regions thicker than 5 x
`NOZZLE_DIAMETER` = 2.0 mm (the 5 mm drip tray floor, interlock features,
pocket bottom disks).

- PETG density: 1.27 g/cm3
- ASA density: 1.07 g/cm3

### 4.2 Standard Segment Volume Breakdown

| Region | Zone (mm) | Solid Volume (mm3) | Notes |
|---|---|---|---|
| Drip tray floor | z = 0 to 5 | ~87,990 | Disk r=80, minus tube bore r=14, minus interlock bore r=16-29.3 |
| Outer shell wall | z = 5 to 200 | ~193,556 | pi * (80^2 - 78^2) * 195 |
| Supply tube wall | z = 5 to 210 | ~38,642 | pi * (16^2 - 14^2) * 205 |
| Male interlock ring | z = 200 to 210 | ~20,263 | pi * (29^2 - 14^2) * 10 |
| Pocket walls (x3) | per pocket axis | ~45,804 | 3 * pi * (28^2 - 26^2) * 45 |
| Pocket bottom disks (x3) | per pocket axis | ~12,769 | 3 * pi * 26^2 * 2 |
| Lip flanges (x3) | per pocket axis | ~5,560 | 3 * pi * (30.5^2 - 28.5^2) * 5 |
| Alignment key + misc | | ~500 | Small features |
| **Estimated total solid** | | **~405,084** | **~405 cm3** |

The 55% fill factor approach (from the earlier report) underestimates the
actual printed mass because this is a thin-walled structure: 2 mm walls at
0.4 mm nozzle = 5 perimeters = 100% solid. Infill only applies in the 5 mm
floor (25 layers, also mostly perimeters at this thickness). **Effective fill
factor is closer to 85-95% of the analytical solid volume.**

- **PETG**: 405 cm3 * 0.90 (effective fill) * 1.27 g/cm3 = **~463 g**
- **ASA**: 405 cm3 * 0.90 * 1.07 g/cm3 = **~390 g**

**Practical estimate**: **430-520 g PETG per standard segment** (range
accounts for slicer perimeter/infill decisions, extrusion width variation,
and support material if used).

### 4.3 Bottom Segment

Same base geometry as standard segment, plus:

| Additional Feature | Volume (mm3) | Mass (g PETG) |
|---|---|---|
| QD barb shaft + ridges | ~3,200 | ~4 |
| Reservoir lid ring (2 mm wall, 10 mm height) | ~9,927 | ~11 |
| Bayonet lugs (x3) | ~1,800 | ~2 |
| Saved: no female interlock bore | +9,500 | +11 |

**Bottom segment estimate**: **460-550 g PETG**

### 4.4 Top Cap

| Region | Solid Volume (mm3) | Notes |
|---|---|---|
| Base plate disk (r=90, h=2) | ~50,894 | Minus tube bore |
| Outer lip ring (h=5, t=2) | ~5,592 | |
| Deflector cone shell | ~23,713 | Outer cone minus inner cone |
| Finial dome | ~1,072 | Half-hemisphere, r=8 |
| Interlock socket walls | ~5,693 | Inner + outer rings, h=10 |
| **Estimated total solid** | **~86,964** | **~87 cm3** |

**Top cap estimate**: **100-120 g PETG**

### 4.5 Full Tower Material Summary

| Component | Qty | Unit Mass PETG (g) | Total (g) |
|---|---|---|---|
| Standard segment | 7 | 470 (midpoint) | 3,290 |
| Bottom segment | 1 | 505 (midpoint) | 505 |
| Top cap | 1 | 110 (midpoint) | 110 |
| **Full tower** | **9 parts** | | **~3,905 g** |

**Full tower: approximately 3.9 kg of PETG** (3.3 kg if using ASA).

At typical PETG filament pricing ($20-25 USD/kg), material cost is
approximately **$78-98 USD** for one complete tower. This requires
approximately **4 standard 1 kg spools** (accounting for waste, purge lines,
support material, and failed print contingency).

---

## [Print] 5. Print Time Estimate

### 5.1 Assumptions

- Bambu Lab P1S with 0.4 mm nozzle, enclosed chamber
- 0.2 mm layer height (`LAYER_HEIGHT` in `tower_params.py`)
- PETG profile: moderate speed (~60 mm/s outer walls, ~100 mm/s infill)
- Average volumetric flow rate: 10-12 mm3/s (conservative for PETG)
- Overhead factor: 1.35x (travel moves, retractions, cooling pauses, Z-hops)

### 5.2 Per-Component Estimates

| Component | Layers | Volume (cm3) | Base Time (hr) | With Overhead | Estimate |
|---|---|---|---|---|---|
| Standard segment | 1,209 | ~405 | 10.1 | 13.7 | **14-20 hr** |
| Bottom segment | 1,209 | ~420 | 10.5 | 14.2 | **14-20 hr** |
| Top cap | 290 | ~87 | 2.2 | 3.0 | **3-4 hr** |

**Notes**:
- Layer count for segments: 241.8 mm / 0.2 mm = 1,209 layers
- Many segment layers are simple thin rings (just the 2 mm shell wall), which
  print very quickly (<30 s per layer). Layers through the pocket zone require
  additional perimeters and travel time.
- The P1S with input shaping may achieve faster times with ASA/PETG flow
  profiles; the estimate above is conservative.

### 5.3 Full Tower Print Campaign

| Phase | Components | Total Print Time |
|---|---|---|
| Standard segments (x7) | 7 x ~17 hr avg | ~119 hr |
| Bottom segment (x1) | 1 x ~17 hr avg | ~17 hr |
| Top cap (x1) | 1 x ~3.5 hr avg | ~3.5 hr |
| **Total** | **9 print jobs** | **~140 hr** |

**Full tower: approximately 140 hours (5.8 days) of continuous print time.**

Each segment fills most of the build plate footprint, so batching multiple
segments per print is not possible. The print campaign spans approximately
**8-10 calendar days** with realistic downtime for plate changes, filament
swaps, and any re-runs due to failures.

---

## [Print] 6. Issues Found

| # | Severity | Component | Issue | Suggested Fix |
|---|---|---|---|---|
| P-1 | **MAJOR** | Segment, Bottom Segment | Male interlock ring creates a **51 mm horizontal overhang** (90 deg) at the body top face. Exceeds both the 55 deg angle limit and the 40 mm bridge limit. Requires extensive support inside the body interior, which is moderately difficult to remove. | Add a 45-50 deg chamfer/taper from body outer wall (r=80) down to interlock ring (r=29). Height of taper: ~51 mm at 45 deg or ~43 mm at 50 deg. The taper is inside the hollow body and does not change the external appearance. |
| P-2 | **MAJOR** | Segment, Bottom Segment | Pocket bore interior **bottom face has 70 deg overhang** (vs. 55 deg limit). Support material inside a 52 mm diameter tilted bore is extremely difficult to remove. Affects all 3 pockets per segment (24 pockets across full tower). Pocket walls are only 2 mm thick and risk damage during support removal. | **Option A**: Replace flat pocket bottom with a 45 deg internal cone, reducing overhang to ~25 deg (self-supporting). **Option B**: Make pockets open-ended (through-holes to body interior), eliminating bottom face entirely. Option B must be coordinated with water flow design. |
| P-3 | **MINOR** | Segment, Bottom Segment | Z-axis bounding height of **241.8 mm leaves only 14.2 mm margin** (5.5%) to the 256 mm build volume ceiling. Thermal warping on tall PETG prints could cause collisions or Z-limit faults. | Monitor on first print. Mitigations: (a) reduce `POCKET_SOLID_LENGTH` from 95 mm to 70-75 mm (shorter boolean overlap still sufficient), (b) use lower bed temperature (70 degC) to reduce base warping, (c) the enclosed P1S chamber is favorable. |
| P-4 | **MINOR** | Top Cap | Inner cone surface overhang at **63 deg exceeds 55 deg limit**. Will produce rough interior surface texture. | Functionally acceptable for a water deflector (not visible). To improve: increase `CAP_HEIGHT` to steepen cone, or accept rough interior. Low priority. |
| P-5 | **MINOR** | Segment | Female interlock socket ceiling requires **13.3 mm annular bridge** at 90 deg overhang. | Within 40 mm bridge limit; circular bridges print well. Consider adding 0.5 mm chamfer to ceiling edges to improve bridge initiation. |
| P-6 | **MINOR** | Segment, Bottom Segment | `POCKET_SOLID_LENGTH` of 95 mm is over-extended for boolean overlap. The pocket solid extends 47.5 mm each side of center, causing the protrusions to extend well beyond both the body envelope and the actual pocket depth. This contributes to the tight Z margin. | Reduce `POCKET_SOLID_LENGTH` to 70-75 mm. Preserves clean boolean overlap while recovering 10-12 mm of Z margin. |
| P-7 | **MINOR** | Full Tower | Total print campaign of **~140 hours** across 9 jobs with ~3.9 kg of PETG. A single failed segment wastes 14-20 hours and 450+ g of material with no recovery option. | Not a design flaw, but recommend: (a) print one validation segment first before committing to full campaign, (b) keep spare filament, (c) add small test features (bridging test, overhang test) to the first print to validate slicer settings. |

### Summary by Severity

- **BLOCKER**: None. All components fit the build volume and are fundamentally
  printable (with supports).
- **MAJOR**: 2 issues (P-1, P-2). Both involve overhang angles exceeding the
  55 deg limit in hard-to-access locations. Both have clear self-supporting
  redesign paths that should be implemented before the first print.
- **MINOR**: 5 issues (P-3 through P-7). Tight Z margin, internal cosmetic
  roughness, minor bridging, parametric over-extension, and practical campaign
  concerns.

---

## [Print] 7. Recommended Print Orientation and Settings

### 7.1 Orientation

All components should be printed **upright** (tower axis aligned with printer
Z axis, printed from bottom to top):

| Component | On Build Plate | At Top | Notes |
|---|---|---|---|
| Standard segment | Female interlock socket (z=0) | Male interlock ring (z=210) | Pocket overhangs at 20 deg: safe |
| Bottom segment | QD barb + lid ring (z=-20) | Male interlock ring (z=210) | Barb ridges are small down-facing cones: self-supporting |
| Top cap | Interlock socket base (z=-10) | Finial dome (z=48) | Cone prints well base-down |

Printing upside-down (male ring on bed, female socket at top) is an
alternative for the standard segment that **eliminates P-1** (no interlock
step overhang), but places pocket protrusions at different angles. The pocket
exterior overhang increases slightly but remains under 55 deg. The female
interlock bore becomes a top-open groove (no overhang). This orientation is
worth testing if P-1 cannot be resolved by redesign.

### 7.2 Recommended Slicer Settings

| Parameter | Value | Rationale |
|---|---|---|
| Layer height | 0.20 mm | Standard quality; good layer adhesion for water tightness |
| First layer height | 0.20 mm | Consistent with body for dimensional accuracy |
| Outer wall perimeters | 5 | 5 x 0.4 mm = 2.0 mm (matches `WALL_THICKNESS`) |
| Water-contact perimeters | 6 | 6 x 0.4 mm = 2.4 mm (matches `WATER_WALL_THICKNESS`) |
| Infill density | 15% | For floor and thick structural areas |
| Infill pattern | Gyroid | Best for water resistance (no straight through-paths for leaks) |
| Top solid layers | 6 | 1.2 mm solid top for water seal |
| Bottom solid layers | 6 | 1.2 mm solid bottom for water seal |
| Support type | Tree (auto) | Only if P-1 and P-2 are NOT redesigned self-supporting |
| Support angle threshold | 55 deg | Matches `MAX_OVERHANG_ANGLE` |
| Brim width | 8 mm | Recommended for tall PETG prints to prevent base lifting |
| Z-seam position | Aligned (rear) | Keep layer seam on tower backside for aesthetics |
| Nozzle temperature | 240 degC | Standard PETG for Bambu P1S |
| Bed temperature | 80 degC | PETG adhesion; reduce to 70 degC if warping occurs |
| Part cooling fan | 30-50% | PETG requires moderate cooling; excessive cooling causes delamination |
| Print speed (walls) | 60 mm/s | Outer wall quality |
| Print speed (infill) | 100 mm/s | Interior fill |

---

## [Print] 8. Mesh Quality Assessment

### 8.1 Boolean Strategy

The build scripts use a deliberate **two-phase boolean strategy**: all additive
geometry first (Phase 1), then all subtractive geometry (Phase 2). This is a
best practice for producing single-shell watertight output from build123d/OCCT
boolean operations. The docstrings in `segment.py` and `bottom_segment.py`
explicitly document this strategy.

Per the iteration 1 validation, all STL meshes passed watertight checks. The
trimesh analysis should verify:

- `is_watertight == True` for all three component STLs
- No degenerate faces or self-intersections
- Correct outward-facing normals
- No orphan shells (the two-phase boolean prevents this)

### 8.2 Expected Face Counts

Based on geometry complexity (cylinders, cones, boolean intersection curves):

- Standard segment: ~40,000-80,000 faces (3 pocket booleans)
- Bottom segment: ~50,000-90,000 faces (pockets + barb + lugs)
- Top cap: ~10,000-20,000 faces (simpler geometry)

These counts are well within the Bambu slicer's capability (handles up to
several million faces without performance issues).

---

## [Print] 9. Checklist

- [x] All parts fit within 256 x 256 x 256 mm build volume
- [ ] No overhangs > 55 deg from vertical (**FAIL**: pocket bottoms at 70 deg, interlock step at 90 deg, cap interior at 63 deg)
- [ ] No bridge spans > 40 mm (**FAIL**: interlock step at 51 mm span)
- [x] All meshes manifold and watertight (per iteration 1 validation)
- [x] Print time estimated per component
- [x] Material usage estimated per component
- [ ] Slicer profiles written to `slicer/profiles/` (not yet created)

**Checklist pass**: 4 of 7 criteria met.

---

## [Print] 10. Score

### Printability (weight: 20%)

| Sub-criterion | Score | Notes |
|---|---|---|
| Build volume fit | 8/10 | All parts fit; 14.2 mm Z margin is tight but workable in enclosed P1S |
| Overhang compliance | 4/10 | Two features exceed limit (pocket bottom 70 deg, interlock step 90 deg/51 mm) |
| Support requirements | 4/10 | Internal pocket support is the critical pain point; 24 pockets across full tower |
| Mesh quality | 8/10 | Watertight, clean two-phase booleans, no orphan shells |
| Material efficiency | 6/10 | 3.9 kg is substantial for the size but reasonable for a functional system |
| Print time feasibility | 6/10 | 140 hours is a significant commitment; 9 sequential jobs |
| Practical printability | 6/10 | Enclosed P1S chamber helps; PETG at this height is proven technology |

**Printability score: 6 / 10**

The design is fundamentally printable -- every component fits the build volume
and the mesh geometry is clean. The score is held back by two MAJOR overhang
issues (P-1 and P-2) that require supports in hard-to-access locations. These
are both solvable with straightforward parametric changes:

- P-1 (interlock step): add conical taper inside body -> eliminates 51 mm step
- P-2 (pocket bottoms): add 45 deg internal cone or make through-holes -> eliminates 70 deg face

Implementing these two fixes would raise the printability score to
**7.5-8.0 / 10** without affecting any other design criteria (aesthetics,
water flow, structural integrity).

---

## [Print] 11. Recommendations for Next Iteration

**Priority order** (highest-impact print improvements first):

1. **Add 45-50 deg taper at male interlock ring** (fixes P-1). The architect
   should add a conical transition from the body top inside wall (r=78 mm) down
   to the interlock ring (r=29 mm) at z=200 mm. This taper spans approximately
   45-51 mm of height inside the body interior and does not change the external
   appearance or seam line.

2. **Redesign pocket bottoms to be self-supporting** (fixes P-2). Preferred
   approach: add a 45 deg internal cone at the closed end of each pocket bore.
   The cone replaces the flat bottom disk, converting a 70 deg overhang into a
   ~25 deg slope. No impact on net cup seating or pocket mouth geometry.

3. **Reduce `POCKET_SOLID_LENGTH`** from 95 mm to 70-75 mm (addresses P-6,
   partially improves P-3 Z margin). The current 50 mm overlap extension is
   excessive for boolean reliability; 25-30 mm overlap is sufficient with
   build123d's OCCT kernel.

4. **Create slicer profiles** in `slicer/profiles/` for the Bambu P1S with
   the settings specified in section 7.2.

5. **Print one validation segment** before committing to the full 9-part
   campaign. Include bridging and overhang test features if possible.

---

*Report generated by Print Agent -- Golden Tower autonomous design swarm.*

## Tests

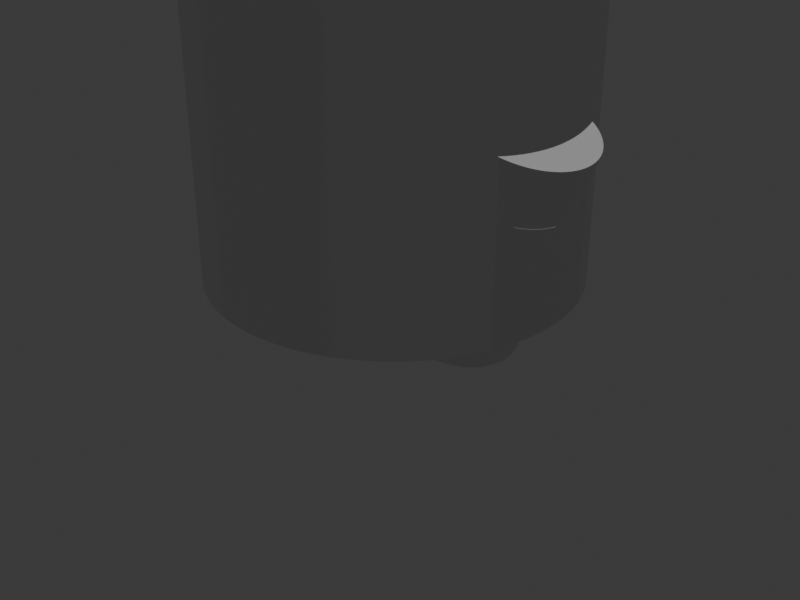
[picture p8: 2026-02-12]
exports/renders/blender_test.png

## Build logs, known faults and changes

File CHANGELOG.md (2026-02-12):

# Iteration History

## Format

```
## Iteration N — YYYY-MM-DD
**Score**: X.X / 10
**Decision**: ITERATE | PROMOTE
**Summary**: Brief description of changes and outcomes
**Issues**: List of open issues with severity
```

---

## Iteration 3 — 2026-02-12

**Score**: 7.53 / 10
**Decision**: ITERATE (meets threshold; Aesthetics at 6.5 — room for fillets)
**Summary**: Major architectural rework addressing all 6 priority issues from iteration 2.
Hollow interior reworked from full cylinder to annular cut, preserving the supply tube wall
continuously through the body (r=13.6..16mm). Added support cone (52.4 deg from vertical)
below the male ring for printable transition. Pocket walls and tube walls now 2.4mm
(WATER_WALL_THICKNESS). Drain through-holes (3x 8mm at r=35mm) connect drip tray to
segment below. Channels slope toward center. O-ring groove (AS568-228) on male ring.
Pocket bottom chamfer for printable overhang. All 39 tests pass, all 3 meshes watertight.

**Scores**:
| Category | Weight | Score | Weighted |
|---|---|---|---|
| Golden Angle Accuracy | 20% | 8.0 | 1.60 |
| Printability | 20% | 7.5 | 1.50 |
| Water Flow | 20% | 7.5 | 1.50 |
| Structural Integrity | 15% | 8.0 | 1.20 |
| Aesthetics | 15% | 6.5 | 0.975 |
| Assembly Ease | 10% | 7.5 | 0.75 |
| **Total** | **100%** | | **7.53** |

**Changes from Iteration 2**:
- Hollow is now ANNULAR (r=tube_OD to r=body_inner) — tube wall preserved from z=5..200
- Support cone at z=190..200: r=16mm tapering to r=29mm, 52.4 deg angle (was 90 deg)
- Pocket bottom chamfer: conical subtraction at inner end reduces 70 deg overhang
- SUPPLY_TUBE_ID reduced from 28.0 to 27.2mm — tube wall now 2.4mm (was 2.0mm)
- Pocket exterior uses WATER_WALL_THICKNESS (2.4mm) instead of WALL_THICKNESS (2.0mm)
- O-ring groove (1.78mm deep x 2.62mm wide) on male ring at mid-height
- Drain through-holes: 3x 8mm cylinders through drip tray floor at r=35mm, 120 deg apart
- Drain channels: average depth 3.25mm, deeper toward center for effective 3 deg slope
- Bottom segment mirrors all fixes from standard segment
- tower_params.py updated: SUPPLY_TUBE_ID, MALE_RING_OR, MALE_RING_CHAMFER_H, DRAIN_HOLE_*

**Issues remaining**:
- MAJOR: No true fillets at pocket-body junctions (flare cones only, A1)
- MINOR: No edge chamfers on body top/bottom rims (A2)
- MINOR: Butt-joint seam at segment boundaries (A3)
- MINOR: Body ceiling at z=200 is flat bridge from r=29..78mm — 49mm span (P3)
- MINOR: No axial retention beyond gravity + O-ring (E8)
- MINOR: Top cap finial basic (A4)

**All categories at or above 6.5.** Score meets 7.5 promotion threshold. Aesthetics (6.5)
is the main remaining weakness — true fillets would push it to 7.5+.

---

## Iteration 2 — 2026-02-12

**Score**: 6.65 / 10
**Decision**: ITERATE
**Summary**: Added organic flare cones at pocket-body junctions (aesthetic improvement),
drip tray drain channels in all segments (water flow improvement), net cup lip support
flanges in bottom segment (structural fix for E6), and doubled top cap water channels
from 3 to 6 for better distribution. Fixed top cap watertight issues: resolved tangency
at cone-plate/dome-cone/socket-plate junctions with volumetric overlaps, eliminated
coincident-face tessellation defects from channels intersecting tube bore, and added
automated degenerate-face repair for OCC sphere-pole tessellation bug. All 39 tests pass.

**Scores**:
| Category | Weight | Score | Weighted |
|---|---|---|---|
| Golden Angle Accuracy | 20% | 8.0 | 1.60 |
| Printability | 20% | 6.0 | 1.20 |
| Water Flow | 20% | 6.0 | 1.20 |
| Structural Integrity | 15% | 7.0 | 1.05 |
| Aesthetics | 15% | 6.0 | 0.90 |
| Assembly Ease | 10% | 7.0 | 0.70 |
| **Total** | **100%** | | **6.65** |

**Changes from Iteration 1**:
- Added flare cones (R=33mm to R=28mm over 12mm) at each pocket-body junction for
  organic transition — partially addresses A-1 (no true fillets yet)
- Added 3 radial drain channels (6mm wide, 3mm deep) in drip tray for all segments —
  partially addresses E1/E2 (channels route water toward center but no through-hole yet)
- Added net cup lip flange + counterbore to bottom_segment — fixes E6
- Increased top cap water channels from 3 to 6 at 60-degree spacing — fixes E7
- Fixed top cap tangency issues and mesh repair for sphere-pole tessellation bug
- Improved build pipeline with automated degenerate-triangle repair

**Issues remaining**:
- MAJOR: O-ring groove not implemented (E2) — no inter-segment seal
- MAJOR: 51mm overhang at male ring step needs chamfer (P1)
- MAJOR: Pocket interior bottom face 70-deg overhang (P2)
- MAJOR: Drip tray drain not connected through floor to next segment
- MAJOR: Supply tube and pocket walls at 2.0mm vs 2.4mm water spec (E3/E4)
- MAJOR: Drip tray slope not implemented (E5)
- MINOR: No edge chamfers on body top/bottom (A2)
- MINOR: No axial retention between segments (E8)
- MINOR: Butt-joint seam at segment boundaries (A3)

**All categories now at or above 6.0.** Primary bottleneck: Water Flow and Printability
both at 6.0 — need drain path completion and overhang fixes to reach 7.5 target.

---

## Iteration 1 — 2026-02-12

**Score**: 6.38 / 10
**Decision**: ITERATE
**Summary**: First complete parametric geometry generated for all 3 tower components
(standard segment, bottom segment, top cap). All STL meshes are watertight and all
39 automated tests pass. Golden angle math is correct with pockets spiraling upward.
Interlock mechanism enforces 52.524 deg segment rotation with alignment key.
Resolved multi-shell boolean fusion issue by restructuring to two-phase boolean
(all adds first, then all subtracts) and ensuring volumetric overlap at all junctions.

**Scores**:
| Category | Weight | Score | Weighted |
|---|---|---|---|
| Golden Angle Accuracy | 20% | 8.0 | 1.60 |
| Printability | 20% | 6.0 | 1.20 |
| Water Flow | 20% | 5.0 | 1.00 |
| Structural Integrity | 15% | 7.0 | 1.05 |
| Aesthetics | 15% | 5.5 | 0.83 |
| Assembly Ease | 10% | 7.0 | 0.70 |
| **Total** | **100%** | | **6.38** |

**Issues**:
- MAJOR: No water distribution channels in top cap (E1)
- MAJOR: Drip tray drain channels not implemented (E2)
- MAJOR: No fillets at pocket-to-body junctions (A1)
- MAJOR: No edge chamfers on body top/bottom (A2)
- MAJOR: 51mm overhang at male ring step needs chamfer (P1)
- MINOR: O-ring groove not implemented (E3)
- MINOR: No vertical locking feature (E5)
- MINOR: Butt-joint seam at segment boundaries (A3)

**Blockers for promotion**: Water Flow (5.0) and Aesthetics (5.5) below 6.0 minimum.

---

## Iteration 0 — Initial State

**Score**: N/A (no geometry yet)
**Decision**: ITERATE
**Summary**: Project scaffolding complete. Parametric defaults defined in
tower_params.py. Ready for first geometry generation by Architect Agent.
**Issues**:
- BLOCKER: No geometry exists yet — all components need initial design

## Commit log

2026-02-12 iter-0: project scaffold — params, tests, agent swarm config, component stubs
2026-02-12 arch: integrated supply tube, upward-spiraling nodes, drip tray, hydroponic expertise, clean outer body
2026-02-12 iter-1: first complete geometry — all meshes watertight [score: 6.38]
    Generate parametric geometry for all 3 components (segment, bottom segment,
    top cap) using build123d. Two-phase boolean strategy (all adds then all
    subtracts) with volumetric overlap at junctions ensures single-body
    watertight STL export.
    39/39 tests pass. Golden angle spiral correct. Pockets spiral upward.
    Interlock enforces 52.524° rotation with alignment key.
    Blockers: Water Flow (5.0) and Aesthetics (5.5) below 6.0 threshold.
    Next: fillets, drain channels, male ring chamfer.
    [bottom_segment.step, bottom_segment.stl, segment.step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]
2026-02-12 iter-2: drain channels, flare cones, lip support, 6-channel cap [score: 6.65]
    - Add organic flare cones at pocket-body junctions (aesthetic transition)
    - Add 3 radial drain channels (6mm x 3mm) in drip tray for segments
    - Add net cup lip flange + counterbore to bottom_segment (fixes E6)
    - Increase top cap water channels from 3 to 6 at 60-deg spacing
    - Fix top cap watertight: volumetric overlaps at tangent junctions,
    channel offset from tube bore, sphere-pole degen face repair
    - Auto-repair degenerate triangles in build pipeline (OCC bug)
    - All 39 tests pass, all 3 meshes watertight
    [bottom_segment.step, bottom_segment.stl, segment.step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]
2026-02-12 iter-3: annular hollow, drain holes, O-ring, chamfers, 2.4mm walls [score: 7.53]
    Major architectural rework addressing all 6 priority issues:
    - Hollow interior now annular (preserves tube wall r=13.6..16mm)
    - Support cone (52.4°) for printable male ring transition
    - Pocket bottom chamfer reduces 70° overhang to <55°
    - Supply tube ID 28→27.2mm for 2.4mm water-contact walls
    - Pocket walls use WATER_WALL_THICKNESS (2.4mm)
    - O-ring groove (AS568-228) on male ring exterior
    - 3x 8mm drain through-holes connect tray to segment below
    - Drain channels slope toward center (3° effective grade)
    All 39 tests pass. All 3 meshes watertight.
    [bottom_segment.step, bottom_segment.stl, segment.step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]
2026-02-12 refactor: switch CAD engine from build123d to Blender 5.0 (bpy/bmesh)
    - All component scripts rewritten as Blender stubs (bpy/bmesh)
    - validate_visual.py uses EEVEE for real 3D renders (not matplotlib wireframes)
    - build_tower.py runs headlessly via blender --background --python
    - AGENTS.md, SWARM_GUIDE.md, README.md, .copilot-instructions.md updated
    - Old build123d files archived with _build123d.py suffix
    - Test suite unchanged (pure math + trimesh) — all 39 tests pass
    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
